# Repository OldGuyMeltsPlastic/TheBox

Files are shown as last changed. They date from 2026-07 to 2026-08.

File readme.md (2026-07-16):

# TheBox - An INDX-ready DoomCube-Trident 350 Build Log

This repository documents the engineering, CAD optimization, physical wiring architecture, and initial Klipper firmware configuration for a highly modified, heavy-duty, custom-sized **Voron Trident** variant integrated into a **DoomCube** enclosure ecosystem. The design targets a true cubic build volume of **355mm x 355mm x 355mm** with optimized toolhead overtravel for localized sub-systems.

---

## 📐 1. Frame Geometry & Structural Layout

Unlike standard 2020-based Voron builds, this frame scales up structural rigidity significantly by utilizing thick Euro-profile aluminum extrusions for the load-bearing pillars, establishing an asymmetric, inner-flush framework.

*   **Vertical Z-Axis Corner Pillars:** 4420 Euro-Profile Extrusions (40mm x 20mm), **880mm height**.
*   **Horizontal Perimeter Frame (Outer Crossmembers):** 4420 Euro-Profile Extrusions, **520mm length** (top/bottom perimeters).
*   **Gantry Moving X-Axis Rail Extrusion:** Standard 2020 aluminum profile extrusion, **480mm length**.
*   **Bed Support Matrix:** Standard 2020 aluminum profile extrusions.
*   **Mounting Alignment:** All internal 2020 gantry and bed framework extrusions mount strictly **flush with the inside edge** of the 4420 Z-pillars. This layout preserves standard interior kinematic spacing while pushing the extra 20mm profile width outward to function as a rigid exterior chassis.

### 🗺️ Vertical Coordinate Map (Z-Axis Stack)
*   **Z = 0mm to 40mm:** Bottom 4420 horizontal frame profile baseline.
*   **Z = 40mm to 560mm:** Clear mechanical workspace gap (**520mm total height**).
*   **Z = 560mm to 580mm:** Fixed XY Gantry plane (2020 gantry extrusion location).
*   **Z = 580mm to 880mm:** Overhead workspace clearance (**300mm total height**) reserved for toolhead electronics umbilical loops, remote CPAP air hose path loops, and DoomCube Top Hat design clearance.

---

## 🏎️ 2. Kinematics & Motion System

The motion system is built for ultra-high acceleration and high-torque execution to counteract the mass penalty of heavy, all-metal CNC components.

### X/Y CoreXY Axis Configuration
*   **Gantry System:** LDO Monolith CNC Aluminum Gantry Kit.
*   **Drive Configuration:** 4-Motor All-Wheel Drive (AWD).
*   **Motors:** 4x High-Torque LDO-42STH48-2804AH Steppers.
*   **Linear Guides (Y-Axes):** 2x Hiwin MGN9H Linear Rails, **450mm length**. Accounting for the 39.9mm length of the carriage block, the raw physical Y travel boundary is capped at **410.1mm**.
*   **Linear Guide (X-Axis):** Hiwin MGN12H Linear Rail, **450mm length**. Accounting for the 45.4mm length of the carriage block, the raw physical X travel boundary is capped at **404.6mm**.
*   **Belts & Pulleys:** True 9mm wide genuine Gates GT2 (2GT) EPDM belts. GT1.5 modifications were avoided to preserve high-tension torque transfer, prevent tooth shear during high-acceleration spikes, and maintain standard Monolith parallel tracking geometries.
*   **Spatial Clearance:** Because the gantry mounts flush to the inner edge of the frame, the AWD rear stepper pods have 100% mechanical clearance without risking any physical collision with the wider 40mm faces of the 4420 Z corner pillars during deep Y-travel moves.

### Z-Axis Configuration
*   **Kinematic Style:** True Trident 3-point kinematic bed leveling suspension.
*   **Z Steppers:** 3x LDO-42STH48-1684CL500E Motors with integrated **500mm Tr8x4 Lead Screws**.
*   **Linear Guides:** 3x 500mm Hiwin MGN9H Linear Rails.
*   **Layout Orientation:** Single Z-axis lead screw and rail centered at the **rear** of the frame (sharing space with the main vertical cable drag chain); dual Z-axis assemblies tucked into the **front-left** and **front-right** corners. This layout preserves a completely wide-open front path for standard DoomCube enclosure doors.
*   **Mounting Method:** CNC Aluminum Trident Z-axis mounts and linear rails are bolted directly into the internal-facing 20mm slot of the 4420 vertical extrusions to maintain strict linear parallelism.

---

## 🛏️ 3. Custom Bed Frame & Thermal Kinematics

To integrate a 4-point perimeter-mounted build plate onto a 3-point Trident moving Z-axis without modifying precision components, a custom structural H-frame was engineered.

*   **Build Plate:** Standard LDO Voron 2.4 355mm x 355mm Mic6 Aluminum Plate (lacks a center-rear mounting hole).
*   **Custom H-Frame Dimensions:** 
    *   *Front Extrusion:* 2020 profile, **520mm length**.
    *   *Rear Extrusion:* 2020 profile, **350mm length**.
    *   *Center Spine Cross-Piece:* 2020 profile, **320mm length**.
    *   *Joint Fasteners:* Blind joints secured via heavy-duty M6 x 16mm bolts.
*   **Kinematic Suspension:** Whopping Pochard / Lightweight Labware Voron 2.4 CNC Kinematic Bed Mounts Kit. 
    *   The long black aluminum cross-yoke plate connects to the rear two corner holes of the 2.4 plate, pivoting on a center dowel pin.
    *   The front two corner holes couple via leaf-spring tabs to magnetic pins on the 520mm front extrusion, eliminating thermal expansion warping ("taco effect").

---

## 🧠 4. Control System & Power Architecture

The brain and power infrastructure utilizes a split-bus strategy to safely mix high-performance high-voltage motion with delicate logic and auxiliary components.

### Hardware Component Matrix
*   **Host Computer:** Raspberry Pi 4B.
*   **Main MCU Controller:** BigTreeTech Octopus Max EZ.
*   **Stepper Drivers:** BTT EZ5160 Pro RGB Drivers (high-voltage external MOSFET versions).
*   **Triple-Bus Power Supply Array:**
    *   *System Logic & Pi:* Mean Well RS-25-5 (5V, 5A output).
    *   *Heaters, Fans, & Z-Axis:* Mean Well UHP-200-24 (24V, 8.4A fanless low-profile supply).
    *   *High-Performance AWD Stepper Rail:* Mean Well UHP-200-55 (55V, 3.6A fanless low-profile supply).

### Physical Wiring Topology & Terminal Isolation
Because the Octopus Max EZ organizes its high-power paths into discrete, isolated block sectors, power lines are routed into three completely separate input terminal clusters on the board:

```ini
[Mean Well RS-25-5]  ---> (5V Output)  --->  DCIN Terminal (Logic Bus)
[Mean Well UHP-200-24] ---> (24V Output) --->  MOTOR_M5-M8 Power Input Bank (Z-Axis & Extruder)
[Mean Well UHP-200-55] ---> (55V Output) --->  MOTOR_M1-M4 Power Input Bank (AWD Gantry Only)
```

*   **⚠️ Unified Grounding Protocol:** The Negative (V-) terminals of all three Mean Well power supplies are wired together with a heavy-gauge jumper wire to create a single, unified reference ground across the entire machine chassis. Leaving the supplies unbonded will drop the tmc5160 reference baseline, causing erratic positioning errors or hardware damage.
*   **Driver Jumper Mapping:** The Octopus Max EZ features pinless driver routing logic; no manual jumper caps are required beneath the EZ5160 drivers to activate SPI communication.
*   **Physical Endstop Routing:** Physical microswitches or proximity sensors are utilized for X and Y homing bounds. **Do not populate the physical DIAG jumpers** on the Octopus Max EZ board for slots M1 through M4, as StallGuard sensorless homing is disabled in favor of hardware switches.
*   **Voltage Isolation Constraints:** The Z-axis and Extruder stepper motors are strictly isolated on the 24V rail. Running them at 55V offers no performance benefit at low RPMs and introduces extreme thermal heat-soak risk into the compact aluminum toolhead/filament path.

---

## 🛠️ 5. Integrated Sub-Systems & Performance Thresholds

### Toolhead & Nozzle Ecosystem
*   **Hotend:** Chube Conduction High-Flow Hotend (rigid-mounted flat face directly to an aluminum cooling/mounting block).
*   **Extruder:** CNC Aluminum Sherpa Mini driven by a lightweight, high-temperature LDO-42STH20-1004ASH(IG7T) 20mm pancake motor.
*   **Nozzle Geometry:** Bozzle 0.5mm Tungsten Carbide Nozzle. Selected to deliver extreme thermal throughput with structural resistance against abrasive fiber-filled polymers (CF-ASA / GF-Nylon). Sliced extrusions baseline at a `0.55mm` nominal line width.
*   **Part Cooling System:** Remote high-pressure CPAP blower fan delivering compressed air via a flexible hose, stripping heavy cooling fans completely off the moving gantry mass.

### Toolhead & Bed Mesh Sensor
*   **Bed Mesh Sensor:** Cartographer 3D Eddy-Current Sensor.
    *   *Calibration Target:* Sensor coil positioned exactly **3.0mm higher than the nozzle tip**.
    *   *Keep-Out Zone:* Specialized printed or non-metallic mounts required to prevent the LDO Monolith CNC aluminum components from distorting the eddy current magnetic sensor field.

### Performance & Slicer Targeting
Given the 55V rail pushing a 9mm EPDM drive train, the motion boundaries are structurally unconstrained. Real-world speeds are throttled by the volumetric flow properties of the Chube+Bozzle cluster (~50 mm³/s).
*   **Daily Max Print Velocity:** **350 mm/s** for a standard `0.25mm` layer height baseline.
*   **Outer Perimeter Target:** **200 to 220 mm/s** for perfect surface finish and gloss distribution.
*   **Target Acceleration:** **15,000 to 20,000 mm/s²** for regular execution, peaking up to **25,000+ mm/s²** for travel transitions via Klipper Input Shaper tuning.
*   **Belt Tuning Metric:** 9mm EPDM belts are highly tensioned to a target frequency of **140 Hz to 160 Hz** on parallel runs to maximize input shaper structural data collection.

### Off-Plate Purge System
*   **X-Axis Overtravel Budget:** Centering the 355mm build plate within the 404.6mm raw X carriage boundary leaves exactly **24.8mm of spatial clearance** on both the left and right sides of the bed.
*   **Y-Axis Overtravel Budget:** Bounded by the 450mm rail length, the 410.1mm raw Y carriage travel yields **55.1mm of structural overtravel**, offering roughly 27.5mm of clearance beyond the front and rear borders of the bed plate.
*   **Purge Hardware:** *nitjsefni's* Frame-Mounted Trident Purge Bucket & Nozzle Brush System (Remixed from Bloodpack's Decontaminator).
    *   *Material:* Printed entirely in **ASA** (5 walls, 40% Gyroid infill) to withstand extreme enclosure ambient temperatures.
    *   *Modifications:* The printed mounting arm is customized in CAD to adapt from a standard 2020 bracket to the specific spacing of the front-left 4420 extrusion pillar, and scaled vertically to compensate for the specific nozzle height of the Chube Conduction vs a standard Rapido UHF.

---

## 💾 6. Comprehensive Klipper `printer.cfg` Codebase

```ini
#####################################################################
# BTT Octopus Max EZ Split-Voltage Firmware Baseline Configuration
# 55V Bus: Drivers M1-M4 (AWD CoreXY) | 24V Bus: Drivers M5-M8 (Z & Extruder)
#####################################################################

[mcu]
serial: /dev/serial/by-id/usb-Klipper_stm32h723xx_BTT-Octopus-Max-EZ-if00

[printer]
kinematics: corexy
max_velocity: 600
max_accel: 25000
max_z_velocity: 15
max_z_accel: 350
square_corner_velocity: 8.0

#####################################################################
# 🏎️ AWD HIGH-VOLTAGE MOTOR CONFIGURATION (55V BUS)
# Drivers: BTT EZ5160 Pro RGB | Motors: LDO-42STH48-2804AH
#####################################################################

# --- STEPPER X (Front-Left AWD Motor - Slot M1) ---
[stepper_x]
step_pin: PC6
dir_pin: !PA14       # Adjust direction inversion (!) during calibration checkout
enable_pin: !PC7
rotation_distance: 40
microsteps: 16
full_steps_per_rotation: 200
endstop_pin: ^PF0    # Physical hardware endstop switch connected to PF0 (Pull-up enabled)
position_min: -24    # Maximum physical left overtravel bound of the 450mm X rail
position_endstop: 0
position_max: 380    # Total physical carriage limit relative to homed zero reference

[tmc5160 stepper_x]
cs_pin: PD12
spi_software_sclk_pin: PE12
spi_software_mosi_pin: PE14
spi_software_miso_pin: PE13
sense_resistor: 0.050        # ⚠️ CRITICAL CORRECTED VALUE FOR BTT RGB PRO DRIVERS
run_current: 1.75
interpolate: False
stealthchop_threshold: 0     # SpreadCycle forced for maximum tracking torque

# --- STEPPER X1 (Rear-Right AWD Motor - Slot M2) ---
[stepper_x1]
step_pin: PD3
dir_pin: !PD2
enable_pin: !PD4
rotation_distance: 40
microsteps: 16
full_steps_per_rotation: 200

[tmc5160 stepper_x1]
cs_pin: PD5
spi_software_sclk_pin: PE12
spi_software_mosi_pin: PE14
spi_software_miso_pin: PE13
sense_resistor: 0.050
run_current: 1.75
interpolate: False
stealthchop_threshold: 0

# --- STEPPER Y (Front-Right AWD Motor - Slot M3) ---
[stepper_y]
step_pin: PB3
dir_pin: !PB2
enable_pin: !PA5
rotation_distance: 40
microsteps: 16
full_steps_per_rotation: 200
endstop_pin: ^PF1    # Physical hardware endstop switch connected to PF1 (Pull-up enabled)
position_min: -10    # Allows small forward clearance overtravel
position_endstop: 375 # Backstop boundary homing baseline targeting the 450mm Y rail
position_max: 375

[tmc5160 stepper_y]
cs_pin: PA6
spi_software_sclk_pin: PE12
spi_software_mosi_pin: PE14
spi_software_miso_pin: PE13
sense_resistor: 0.050
run_current: 1.75
interpolate: False
stealthchop_threshold: 0

# --- STEPPER Y1 (Rear-Left AWD Motor - Slot M4) ---
[stepper_y1]
step_pin: PD11
dir_pin: !PD10
enable_pin: !PD12
rotation_distance: 40
microsteps: 16
full_steps_per_rotation: 200

[tmc5160 stepper_y1]
cs_pin: PD13
spi_software_sclk_pin: PE12
spi_software_mosi_pin: PE14
spi_software_miso_pin: PE13
sense_resistor: 0.050
run_current: 1.75
interpolate: False
stealthchop_threshold: 0

#####################################################################
# 🛏️ TRIDENT Z-AXIS MOTOR CONFIGURATION (24V BUS)
# Drivers: Standard TMC5160 Stepsticks | Motors: LDO-1684CL500E
#####################################################################

# --- STEPPER Z (Front-Left Z Motor - Slot M5) ---
[stepper_z]
step_pin: PA10
dir_pin: PA9
enable_pin: !PA13
rotation_distance: 4
microsteps: 16
endstop_pin: probe:z_virtual_endstop # Pinless configuration utilizing Cartographer Touch
position_max: 355
position_min: -5

[tmc5160 stepper_z]
cs_pin: PA11
sense_resistor: 0.075 # Set to match standard stepstick parameters used for Z
run_current: 1.00
interpolate: False
stealthchop_threshold: 0

# --- STEPPER Z1 (Rear Center Z Motor - Slot M6) ---
[stepper_z1]
step_pin: PC9
dir_pin: PC8
enable_pin: !PC10
rotation_distance: 4
microsteps: 16

[tmc5160 stepper_z1]
cs_pin: PA8
sense_resistor: 0.075
run_current: 1.00
interpolate: False
stealthchop_threshold: 0

# --- STEPPER Z2 (Front-Right Z Motor - Slot M7) ---
[stepper_z2]
step_pin: PG7
dir_pin: PG6
enable_pin: !PC11
rotation_distance: 4
microsteps: 16

[tmc5160 stepper_z2]
cs_pin: PG8
sense_resistor: 0.075
run_current: 1.00
interpolate: False
stealthchop_threshold: 0

#####################################################################
# 🪶 EXTRUDER CONFIGURATION (24V BUS)
# Extruder: CNC Sherpa Mini | Motor: LDO-42STH20-1004ASH(IG7T)
# Driver: BTT EZ5160 Pro RGB (Slot M8)
#####################################################################

[extruder]
step_pin: PE6
dir_pin: !PA15          # Sherpa Mini typically requires mechanical direction inversion
enable_pin: !PE1
rotation_distance: 22.67895
gear_ratio: 50:10       # 50:10 internal drive cluster teeth count
microsteps: 16
full_steps_per_rotation: 200
nozzle_diameter: 0.500  # Updated for Bozzle 0.5mm configuration
filament_diameter: 1.750
max_extrude_only_distance: 1400.0
pressure_advance: 0.025 # Baseline starting value for Sherpa + Bozzle cluster

# --- Chube Conduction High-Temp Sensor ---
heater_pin: PA2
sensor_type: PT1000     # Native Chube precision high-temperature sensor RTD element
sensor_pin: PF4         # Tied directly to standard Octopus Analog Input channel
pullup_resistor: 4700
min_temp: 0
max_temp: 350

[tmc5160 extruder]
cs_pin: PC13
spi_software_sclk_pin: PE12
spi_software_mosi_pin: PE14
spi_software_miso_pin: PE13
sense_resistor: 0.050   # ⚠️ CRITICAL CORRECTED VALUE FOR BTT RGB PRO DRIVERS
run_current: 0.70       # Maintained at 70% thermal headroom ceiling to prevent heat creep
interpolate: False
stealthchop_threshold: 0

#####################################################################
# 🌬️ PART COOLING CPAP REMOTE BLOWER SYSTEM & SENSORS
#####################################################################

[fan]
pin: PE5                # Tied to high-current hardware PWM Fan Controller pin
hardware_pwm: True
cycle_time: 0.0001      # Specialized cycle time for smooth ESC pulse modulation
kick_start_time: 0.100

[cartographer]
serial: /dev/serial/by-id/usb-Cartographer_3d_sensor_here
speed: 40               # Z probing speed in mm/s
lift_speed: 5           # Z lifting speed after probing in mm/s
backlash_comp: 0.005    # Backlash compensation value
x_offset: 0.0           # X offset of the cartographer sensor relative to the nozzle
y_offset: 25.0          # Y offset of the cartographer sensor relative to the nozzle
trigger_distance: 3.0   # Cartographer trigger distance threshold
trigger_curve: default

[bed_mesh]
speed: 300
horizontal_move_z: 5
mesh_min: 25, 25
mesh_max: 330, 330
probe_count: 15, 15
algorithm: bicubic
```

---

## 🦾 7. Core Automated Calibration & Print Start Macros
Add these custom automation macros directly to your macros.cfg file or append them to the end of printer.cfg. They handle your Cartographer Touch homing logic, execute localized adaptive meshes over your printed parts, and manage the left-side off-bed purge sequence.

```ini
#####################################################################
🦾 SYSTEM PRINT CONTROL WORKFLOWS
#####################################################################

[gcode_macro START_PRINT]
gcode:# --- Establish Configuration Parameters ---
{% set BED_TEMP = params.BED|default(100)|float %}
{% set EXTRUDER_TEMP = params.EXTRUDER|default(240)|float %}

# --- Begin Safety Warm-Up Profile ---
M117 Heating Bed to {BED_TEMP}C...
M140 S{BED_TEMP}             # Begin heating bed plate
G90                          # Use absolute coordinates
M104 S150                    # Preheat extruder nozzle safely below ooze thresholds (150C)
G28                          # Initial global homing sequence

# --- Thermal Saturation Soak ---
M190 S{BED_TEMP}             # Wait for Mic6 bed to fully stabilize at heat target
M117 Executing Z-Tilt Alignment...
Z_TILT_ADJUST                # Perform 3-point independent Z-axis tramming profile
G28 Z                        # Re-home absolute Z axis center line

# --- Localized Adaptive Mesh ---
M117 Generating Cartographer Mesh...
BED_MESH_CALIBRATE ADAPTIVE=1 METHOD=rapid_scan # Scans only the model's actual print layout space

# --- Final Melt Execution ---
G0 X-22 Y10 Z30 F18000       # Move out to the physical left overtravel safety limit
M117 Finalizing Hotend Temp...
M109 S{EXTRUDER_TEMP}        # Heat Chube Conduction to functional melt point

# --- Purge and Scrub Run ---
CLEAN_NOZZLE_AND_PURGE       # Execute cleaning macro sequence before dropping down to the bed
M117 Printing...

[gcode_macro CLEAN_NOZZLE_AND_PURGE]
gcode:
SAVE_GCODE_STATE NAME=clean_nozzle_state
G90
M117 Purging Filament...
# --- Position over the nitjsefni Left Purge Bucket ---
G0 X-22 Y15 Z15 F24000       # Align nozzle tip directly inside the custom ASA arm receptacle
G92 E0                       # Reset extrusion metric
G1 E25 F150                  # Extrude a clean 25mm purge blob to fill the melt chamber
G4 P2000                     # Dwell 2 seconds to allow internal stringing pressure to clear
G92 E0G1 E-1.5 F1500         # Small retract to prevent nozzle tip stringing over the frame

# --- High-Acceleration Nozzle Scrub Sequence ---
M117 Scrubbing Nozzle Tip...
# Rapidly sweep back and forth across the left-side silicone/brass brush assembly
{% for i in range(6) %}
G0 X-22 Y30 F36000
G0 X-5 Y30 F36000
{% endfor %}

# --- Exit to Print Matrix ---
G0 Z5 F3000                  # Lift clear of the bucket rim walls
RESTORE_GCODE_STATE NAME=clean_nozzle_state

[gcode_macro END_PRINT]
gcode:
# --- Safety Engine Shutdown ---
M140 S0                      # Turn off heated bed
M104 S0                      # Turn off Chube hotend heater
M107                         # Kill remote CPAP part cooling blower

# --- Retract and Clear Space ---
G91                          # Relative coordinates
G1 E-5 F300                  # Retract remaining molten filament safely away from the cold-zone
G1 Z10 F3000                 # Instantly drop the bed 10mm down to prevent nozzle scarring
G90                          # Absolute coordinates
G0 X5 Y350 F18000            # Park the gantry at the rear of the frame out of the way

M117 Print Complete.
M84                          # Disable all motor current lines (prevents frame holding heat)
```

---

## ⚠️ 8. Critical CAD Constraints & Assembly Verification Checklist
1. Z-Axis Top Clearance: When the bed frame drives to maximum Z-height (nozzle touching the bed surface), ensure the top tips of the unconstrained 500mm lead screws (ending at ~Z=540mm) safely clear the underside of the moving Monolith AWD gantry blocks.
1. DoomCube Panel Offsets: Because the 4420 frame steps outward by an extra 20mm relative to standard Voron 2020 frame profiles, the outer DoomCube panel corner brackets and hinge blocks must be customized in CAD to accommodate the extra 40mm mounting face.
1. X/Y-Axis Carriage Limits: Your travel limits are bounded directly by your 450mm rail configurations. Do not force manual moves beyond X: -24 or Y: 375, as the linear rail blocks will drive directly into physical hardware barriers.

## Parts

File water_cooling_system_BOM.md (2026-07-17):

### Master Bill of Materials (BOM) — Custom AWD Watercooling Setup

| Qty | Item Name & Sourcing Link | Estimated Cost | Purpose |
| :---: | :--- | :---: | :--- |
| **5** | [VzBoT's Mellow Watercooling Plate](https://www.aliexpress.com/item/1005006093838270.html) | $118.75 | Core cooling plates; mounts directly to all 5 NEMA17 motors |
| **1** | [FREEZEMOD SLMZ-V-T 12V Water Cooler](https://www.ebay.com/itm/395155026620) | $79.38 | Combined 12V pump, reservoir, and dual-fan radiator assembly |
| **2** | [Barrow G1/4 3-Way Block Splitter](https://modmymods.com/barrow-g1-4-thread-3-way-block-splitter-fitting-matte-black-tlft3g-a01.html) | $12.00 | Manifolds to split the loop to parallel motor branches and rejoin them |
| **1** | [Barrow Temperature sensor G1/4](https://www.ftcwatercooling.com/products/barrow-temperature-sensor-g1-4) | $3.95 | Screws directly into return manifold to monitor hot-side fluid temp |
| **10**| [4mm Hose Barb x M5 Male Adapter](https://www.industrialspec.com/shop/fittings/threaded-fittings/metric-threaded-fittings/m5-threaded-fittings/4mm-hose-barb-x-m5-male-adapter-nickel-plated-brass.html) | $14.60 | Threaded adapters to interface the 4mm tubing with the 5 Mellow blocks |
| **1** | [Uxcell G1/4 x 4mm Barb Adapter (Pack of 8)](https://www.walmart.com/ip/Uxcell-Hose-Barb-Fittings-G1-4-x-4mm-Thread-Male-Brass-Pipe-Fitting-Adapter-for-Water/5101037775) | $13.59 | Adapts G1/4 manifold block ports down to run the 4mm ID silicone tubing |
| **1** | [Uxcell Silicone Tubing 4mm ID x 6mm OD (10ft)](https://www.walmart.com/ip/Uxcell-Silicone-Tubing-4mm-ID-x-6mm-OD-Pure-Silicon-Tube-High-Temp-Hose-10ft/5113944607) | $10.99 | High-flexibility silicone routing path for the frame and umbilical lines |
| **1** | [PrimoChill Anti-Kink Coil](https://www.performance-pcs.com/tubing/anti-kink-coils/primochill-anti-kink-coil-3-8in-mblue.html) | $0.99 | Exterior reinforcement coil to prevent tight umbilical bends from collapsing |
| **1** | [2020 Extrusion Profile Cable Clip](https://wezhape.com/products/2020-extrusion-profile-cable-clip) | $14.00 | Frame-mounting clips to cleanly manage and anchor tubing runs |
| **1** | [Water Flow Indicator G1/4](https://www.ebay.com/itm/386407983637) | $10.23 | Inline physical spinner for rapid visual validation of loop flow |
| **Total** | **Custom Watercooling Setup** | **~$278.48** | *Excludes tools, coolant fluid, and structural top-center umbilical mount.* |

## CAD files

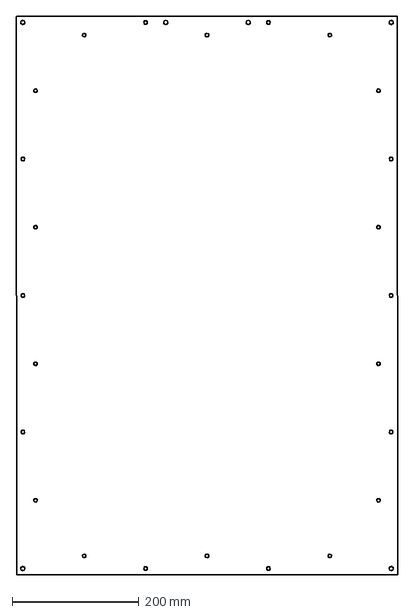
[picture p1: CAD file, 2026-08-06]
DXF/Right Side Panel.dxf
600.0 x 880.0 mm

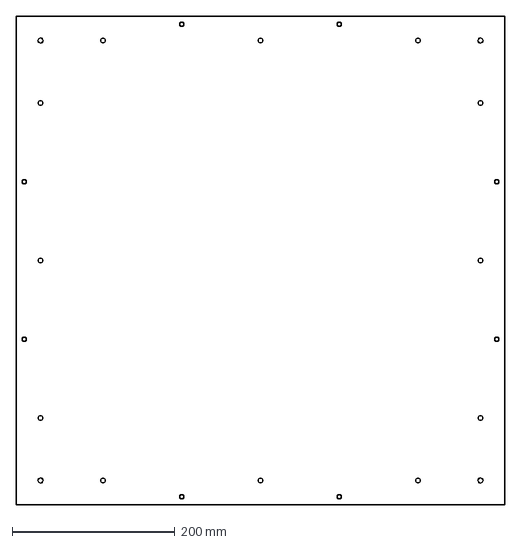
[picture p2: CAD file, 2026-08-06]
DXF/Bottom Panel.dxf
600.0 x 600.0 mm

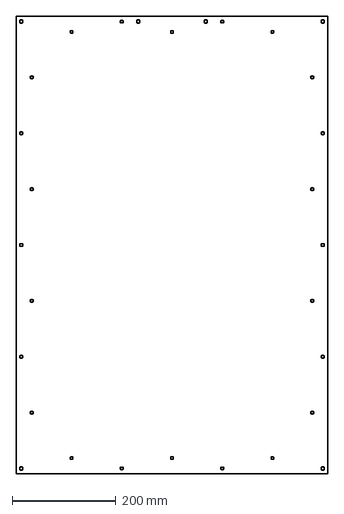
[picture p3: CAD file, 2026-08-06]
DXF/Left Side Panel.dxf
600.0 x 880.0 mm

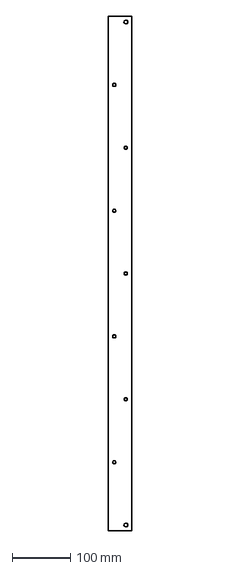
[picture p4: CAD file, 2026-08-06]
DXF/Front Right Post Panel.dxf
40.0 x 880.0 mm

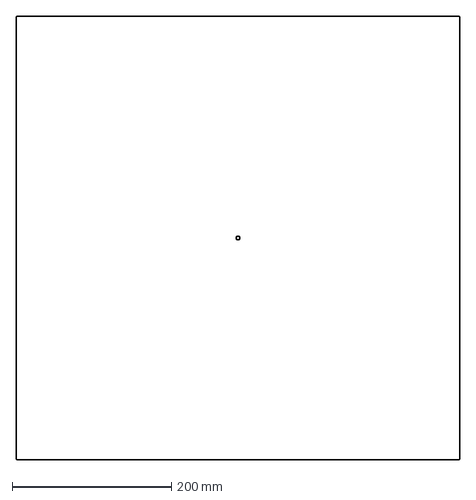
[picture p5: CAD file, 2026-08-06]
DXF/Electronics Bay Top Panel.dxf
557.0 x 557.0 mm

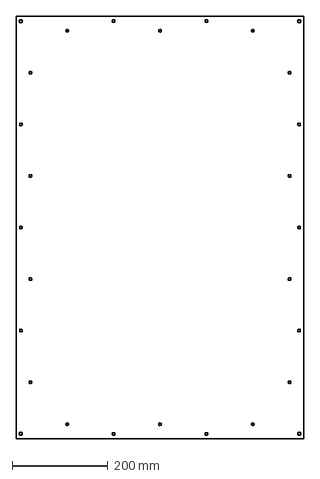
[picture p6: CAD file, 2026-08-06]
DXF/Rear Panel.dxf
600.0 x 880.0 mm

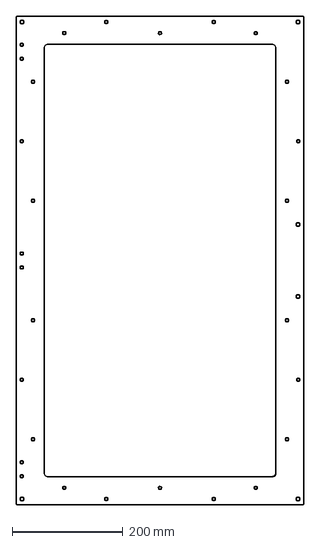
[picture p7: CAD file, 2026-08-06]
DXF/Middle Door Cover Panel.dxf
518.0 x 880.0 mm

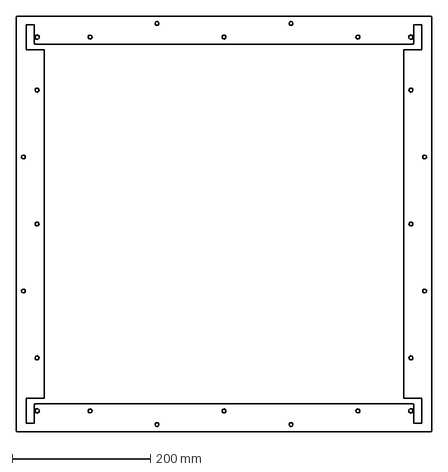
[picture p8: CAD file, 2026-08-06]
DXF/Bottom Motor Wiring Spacer.dxf
600.0 x 600.0 mm

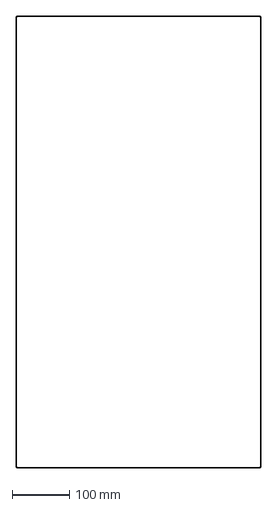
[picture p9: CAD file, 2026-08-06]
DXF/Front Door Window.dxf
427.0 x 789.0 mm

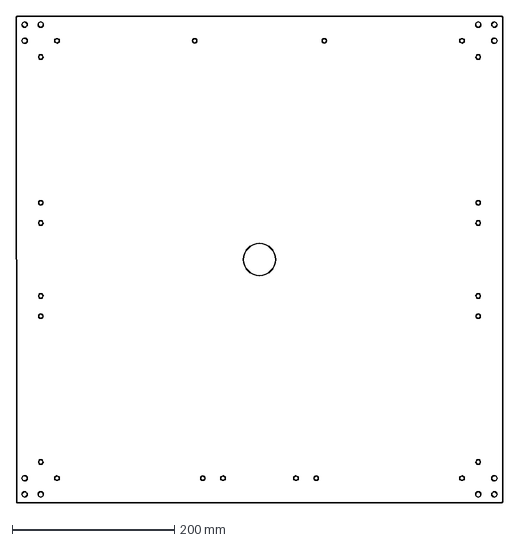
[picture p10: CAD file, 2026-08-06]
DXF/Top Panel.dxf
600.0 x 600.0 mm

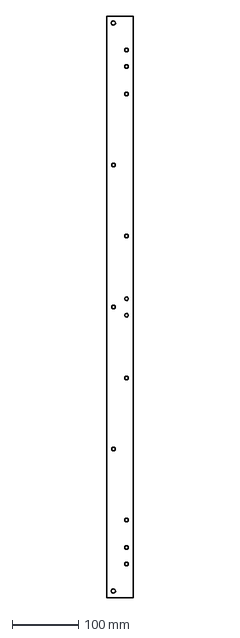
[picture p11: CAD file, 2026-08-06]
DXF/Front Left Post Panel.dxf
40.0 x 880.0 mm

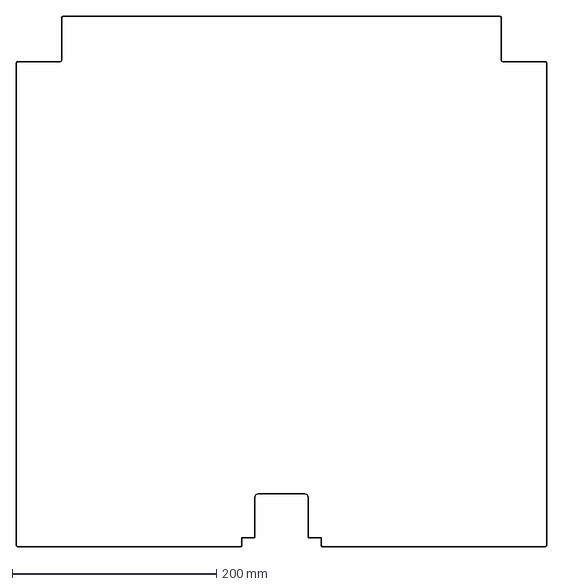
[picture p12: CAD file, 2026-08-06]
DXF/Deck Panel.dxf
519.0 x 519.0 mm

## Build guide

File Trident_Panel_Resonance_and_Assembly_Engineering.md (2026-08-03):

# Enclosure Panel System Engineering Summary

## Executive Summary
This document provides a technical engineering summary of the enclosure panel composite sandwich and structural mounting design for a custom high-performance 3D printer (Voron Trident AWD build, 600x600x880mm frame). 

The analysis evaluates material selection (Aluminum Composite Material vs. Cold Rolled Steel), dynamic resonance behavior at the toolhead, structural shear coupling to 4420 Euro frame extrusions, and high-temperature thermal adhesive strategies for active chamber insulation.

---

## 1. Outer Panel Material Selection: ACM vs. CRS

A critical engineering consideration for high-acceleration 3D printers is minimizing frame-induced resonance transmitted to the toolhead and Input Shaper accelerometer profiles.

### Key Findings
- **ACM (Aluminum Composite Material / Dibond - 3mm):** Features an internal low-density polyethylene (LDPE) viscoelastic core sandwiched between thin aluminum skins. It acts as a native **Constrained-Layer Damper (CLD)**, converting mechanical vibrational energy into low-level thermal energy via shear deformation.
- **CRS (Cold Rolled Steel - 3mm):** Highly stiff ($E \approx 200\text{ GPa}$) and heavy (${\approx}23.5\text{ kg/m}^2$), but possesses an extremely low intrinsic material damping loss factor ($\eta \approx 0.001$). Bare or un-damped CRS acts as an acoustic reflector and drumhead diaphragm, reflecting vibrational energy back into the frame.

---

## 2. Enclosure Composite Sandwich Architecture

The enclosure panel assembly consists of a 3-layer hybrid structural/insulation stack:

```
[ Outer Space ]
      │
┌─────┴─────────────────────────────────────────────────────────────┐
│ Outer Wall: 3mm ACM (Extended 40mm perimeter flange)              │
├───────────────────────────────────────────────────────────────────┤
│ Layer 2:    6mm Cork (Viscoelastic Damping Layer)                 │
├───────────────────────────────────────────────────────────────────┤
│ Layer 3:    18mm PIR Foam (Polyisocyanurate Thermal Barrier)      │
└─────┬─────────────────────────────────────────────────────────────┘
      │
[ Heated Print Chamber (Reflective Foil Inner Face) ]
```

### Stack Dynamics & Configuration
1. **Inset Insulation Layering:** The 6mm cork and 18mm PIR foam layers are dimensioned to sit entirely inset within the inner perimeter walls of the 4420 extrusions.
2. **Exposed Mounting Flange:** The 3mm ACM outer sheet extends **40mm past the cork/PIR stack in all directions**, forming a perimeter-supported mounting flange.
3. **No Foam Crushing:** Because the cork and PIR sit inside the extrusion void rather than beneath the mounting track, the foam layers are completely protected from bolt compression, eliminating the need for rigid internal standoff sleeves.

---

## 3. Structural Frame Coupling & Dual-Track M5 Bolting

The perimeter 40mm ACM flange is bolted flat to the outside faces of the 4420 Euro frame extrusions using **dual tracks of staggered M5 bolts**.

### Dynamic Behavior of the Joint
- **Stressed-Skin Monocoque:** Clamping the outer skin across dual bolt tracks converts the panels into **stressed shear webs**, dramatically increasing overall frame torsional and diagonal rigidity.
- **Micro-Shear Damping at Joint:** Under aggressive $XY$ accelerations and motor pulses, micro-shearing forces pass across the bolted 40mm flange. The LDPE core within the ACM dissipates these shear forces directly at the joint interface.
- **Resonance Profile Impact:** Unlike CRS (which creates sharp, tall resonance peaks that degrade Klipper input shaping limits), the ACM flange yields a broader, heavily damped, low-amplitude resonance profile.

---

## 4. High-Temperature Adhesive Assembly Protocol

Bonding non-porous metal (ACM), porous organic material (Cork), and closed-cell rigid foam (PIR) for an actively heated chamber ($60^\circ\text{C}--80^\circ\text{C}+$) requires an adhesive capable of handling differential thermal expansion without degrading PIR foam.

### Recommended Adhesive: High-Temp Neutral-Cure Silicone (RTV / Mechanical Grade)
- **Examples:** Permatex Ultra Black/Copper, Dow Corning 732, GE Silicone II.
- **Thermal Resistance:** Continuous rating above $150^\circ\text{C}$ ($300^\circ\text{F}+$).
- **Substrate Compatibility:** Neutral-cure formulas emit minimal alcohol/oxime off-gassing and **will not attack or dissolve PIR foam**.
- **Elastomeric Compliance:** Forms a flexible, resilient gasket layer that absorbs micro-movements caused by mismatched thermal expansion coefficients between aluminum, cork, and PIR.

### Step-by-Step Assembly Process
1. **Surface Preparation:**
   - Lightly scuff the inner face of the ACM panel with 120-grit sandpaper to establish mechanical bite.
   - Clean with Isopropyl Alcohol (IPA) and ensure cork/PIR surfaces are dust-free.
2. **ACM to Cork Bonding:**
   - Apply a continuous notched-trowel grid of neutral-cure silicone across the interior region of the ACM.
   - Press the 6mm cork layer into the grid and roll flat with a seam roller.
3. **Cork to PIR Bonding:**
   - Apply a second grid of neutral-cure silicone to the exposed cork face.
   - Press the 18mm PIR foam panel into place with its reflective aluminum foil facing inward toward the print chamber.
4. **Curing:**
   - Place flat plywood/MDF over the sandwich stack and distribute $10--15\text{ kg}$ of weight evenly across the surface for 12–24 hours.

---

## Summary Comparison Matrix

| Property / Feature | 3mm ACM + Cork + PIR Assembly | 3mm CRS + Cork + PIR Assembly |
| :--- | :--- | :--- |
| **Primary Damping Mechanism** | Multi-stage (Viscoelastic LDPE core + viscoelastic cork) | Single-stage (Cork absorption only; steel face reflects energy) |
| **Flange Joint Behavior** | Self-damping shear web (LDPE core absorbs joint energy) | Rigid acoustic reflector (Passes high-frequency energy back into frame) |
| **Toolhead Resonance Impact** | Minimal standing waves; smooth, easily filtered Input Shaper curve | Sharp, high-amplitude resonance peaks; reduced max acceleration limits |
| **Weight Contribution** | High shear stiffness with low added gantry/frame mass | Substantial static weight added to printer chassis |
